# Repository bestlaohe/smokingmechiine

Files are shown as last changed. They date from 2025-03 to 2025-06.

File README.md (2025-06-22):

# 智能焊接吸烟机产品需求文档（PRD）

## 1. 产品概述
便携式多功能焊接辅助设备，集成烟雾抽排、活性炭过滤，焊接照明，电池供电，低功耗，滚轮调节亮度和风扇力度等功能，解决焊接场景下的健康防护与操作便利性问题。

## 2. 核心功能需求

### 2.1 智能吸烟系统
| 指标项 | 技术参数 | 补充说明 |
|---|---|---|
| 风扇类型 | 双滚珠轴承直流风扇（12V/200mA）  | 需提供噪音＜45dB的型号选项 |
| 风道设计 | 螺旋集烟罩+可拆卸滤网 | 滤网需支持水洗重复使用 |
| 调节方式 | 手动无级调速（200-2000rpm） | 响应时间＜3秒 |
| 控制方式 | TIM1_CH2N输出PWM信号(PA2) | PWM频率25KHz，占空比10%-100% |
| 软启动保护 | 0.5秒渐进加速 | 避免启动电流过大 |

### 2.2 专业照明系统
| 组件 | 规格要求 |
|---|---|
| LED光源 | 显色指数≥90，色温5000K±10%，光通量≥800lm | |
| 调光范围 | 10%-100%无级调节 |
| 控制方式 | TIM1_CH1N输出PWM信号(PD0) |
| PWM参数 | 频率2KHz，占空比10%-100% |

### 2.3 人机交互

**控制逻辑：**
1. 短按功能键（0.5s）：通过中断直接处理，切换风扇/灯光控制模式
2. 旋转编码器：在主循环中处理，调节当前模式参数
3. 状态更新：在页面显示函数中统一处理风扇、照明、电池状态更新

**输入设备规格：**
- 旋转编码器：用于调节参数，带有A/B相信号输出
- 功能按键：集成在旋转编码器中，用于切换控制模式
- 检测机制：通过CH32V003端口中断方式检测旋转和按下事件

**显示屏UI规范：**
采用128×128像素GC9107彩色屏幕，实现分区式布局设计：

```
┌──────────────────────┐
│       标题栏         │ ← 0-20像素
├──────────────────────┤
│                      │
│      FAN: 75%        │ ← 21-55像素
│    [■■■■■□□]         │
│                      │
├──────────────────────┤
│                      │
│     LIGHT: 60%       │ ← 56-90像素
│    [■■■■□□□]         │
│                      │
├──────────────────────┤
│                      │
│      BAT: 82%        │ ← 91-125像素
│    [■■■■■■□□]        │
│      4.1V            │
└──────────────────────┘
```

显示内容要求：
- 采用垂直分区设计，清晰展示三个核心参数
- 使用不同颜色区分功能区域：风扇(青色)、照明(黄色)、电池(绿色)
- 电池电量低于20%时进度条变为红色作为警示
- 界面刷新率≥5Hz，支持局部刷新以提高响应速度

### 2.4 显示屏背光
| 组件 | 规格要求 |
|---|---|
| 背光类型 | LED背光 |
| 调光范围 | 10%-100%无级调节 |
| 控制方式 | TIM1_CH3输出PWM信号(PC3) |
| 驱动芯片 | GC9107驱动，分辨率128×128像素，16位色 |

## 3. 结构需求

### 3.1 三防要求
| 参数 | 要求 |
|---|---|
| 防护等级 | IP54防护等级（防尘防溅水） |
| 外壳材料 | 阻燃ABS+硅胶防震包边 |

## 4. 电源管理系统

### 4.1 电池配置
| 参数 | 规格 |
|---|---|
| 电芯类型 | 21700锂离子电池×2（并联） |
| 标称容量 | 5000mAh/3.7V |

### 4.2 续航能力
- 满负荷（风扇+灯光）：≥2h
- 节能模式：≥8h

### 4.3 充电特性
```mermaid
graph TD
    A[Type-C输入] --> B(TP4057管理IC)
    B --> C[恒流充电 1A]
    C --> D[电压≥4.2V转恒压]
    D --> E[截止电流≤100mA停充]
```

## 5. 可靠性要求
| 测试项目 | 验收标准 |
|---|---|
| 高温老化 | 85℃环境下连续工作4小时 |
| 振动测试 | 5-500Hz随机振动3小时 |
| 按键寿命 | 5万次循环无失效 |

## 6. 合规性要求
- 电磁兼容：EN 61000-6-3
- 安规认证：UL 60745-1
- 环保认证：RoHS 2.0

## 7. 成本目标
| BOM分类 | 目标成本（千台量级） |
|---|---|
| 电子部件 | ≤30 |
| 结构件 | ≤50 |
| 合计 | ≤80 |

## 版本记录
| 版本 | 日期 | 修改说明 |
|---|---|---|
| v1.0 | 2023-08-25  | 初始版本 |
| v1.1 | 2023-08-27  | 补充EMC测试要求 |
| v1.2 | 2023-09-20  | 更新UI设计规范 | 
| v1.3 | 2023-10-15  | 调整PWM控制参数，同步软件设计 |

---

## 附录
该文档采用模块化结构设计，包含：
1. 参数表格化呈现关键指标
2. 交互逻辑的时序说明
3. 可视化UI示例
4. 成本分解明细
5. 版本控制记录

如果你觉得有用可以请我喝杯咖啡！
348f36a8640adfb87dfc8b97301e098a

【帅气的带焊接补光的吸烟机-哔哩哔哩】 https://b23.tv/cCpQy1C

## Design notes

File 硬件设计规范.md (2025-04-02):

# 智能焊接吸烟机电路连接定义（修订版）

## 1. 系统电路框图

```
┌──────────────┐          ┌───────────────────────┐          ┌────────────────┐
│              │          │                       │          │                │
│  电源管理模块 │◄─────────┤       主控制器        │──────────►│  显示控制模块  │
│  (TP4057)    │  电压检测 │     (CH32V003)       │  SPI通信  │  (GC9107)      │
│     │        │  充电状态 │                       │          │                │
└─────┼────────┘          └───┬───────┬───────┬───┘          └────────────────┘
      │                       │       │       │
      │                       │       │       │
      │                   PWM控制   PWM控制  旋钮编码
      │                   (PA2)    (PD0)    及按键
      ▼                       │       │       │
┌──────────────┐          ┌───▼───────▼───┐   │    ┌────────────────┐
│ 4.2V锂电池   │          │               │   │    │                │
│              │◄─┐   ┌───►│ 12V升压模块  │   └───►│  人机交互模块  │
└──────────────┘  │   │    │ (MT3608)     │        │  (旋钮+按键)   │
                  │   │    └───┬───────┬──┘        └────────────────┘
            电池管理   │        │       │
            保护电路   │        │       │
                  │   │      12V     12V
                  │   │        │       │
                  │   │        ▼       ▼
                  │   │    ┌──────┐  ┌──────┐
                  │   │    │      │  │      │
                  │   └────┤ 风扇 │  │ 射灯 │
                  │        │ 驱动 │  │ 驱动 │
                  │        └──┬───┘  └──┬───┘
                  │           │         │
                  │           ▼         ▼
                  │        ┌──────┐  ┌──────┐
                  └────────┤      │  │      │
                           │ 风扇 │  │ 射灯 │
                           │ 5cm  │  │ 12V  │
                           └──────┘  └──────┘
```

## 2. 模块间连接关系

### 2.1 主控制器与显示模块连接

| CH32V003引脚 | GC9107引脚 | 信号类型 | 说明 |
|---|---|---|---|
| PC0 | RES | 数字输出 | 复位信号 |
| PC2 | DC | 数字输出 | 数据/命令选择 |
| PC3 | BLK | PWM输出  | 背光亮度控制 |
| PC4 | CS | 数字输出 | SPI片选信号 |
| PC5 | SCL | 数字输出 | SPI时钟信号 |
| PC6 | SDA | 数字输出 | SPI数据信号 |
| 3.3V | VCC | 电源 | 显示模块供电 |
| GND | GND | 电源 | 系统地 |

### 2.2 主控制器与风扇控制电路连接

| CH32V003引脚 | 连接至 | 信号类型 | 说明 |
|---|---|---|---|
| PA2 | MOSFET栅极 | PWM输出  | 控制风扇转速(25KHz) |
| GND | MOSFET源极 | 电源 | 系统地 |
| 12V电源 | 风扇正极 | 电源 | 经MOSFET漏极连接 |

### 2.3 主控制器与LED射灯模块连接

| CH32V003引脚 | 连接至 | 信号类型 | 说明 |
|---|---|---|---|
| PD0 | MOSFET栅极 | PWM输出  | 控制射灯亮度(2KHz) |
| GND | MOSFET源极 | 电源 | 系统地 |
| 12V电源 | 射灯正极 | 电源 | 经MOSFET漏极连接 |

### 2.4 主控制器与人机交互控件连接

| CH32V003引脚 | 连接至 | 信号类型 | 说明 |
|---|---|---|---|
| PD2 | 功能按键 | 数字输入 | 短按切换模式/长按复位 |
| PD3 | 编码器B相 | 数字输入 | 检测旋转方向 |
| PD4 | 编码器A相 | 数字输入 | 检测编码器旋转 |

### 2.5 主控制器与电源管理模块连接

| CH32V003引脚 | 连接至 | 信号类型 | 说明 |
|---|---|---|---|
| PA1 | 电压分压器输出 | 模拟输入 | 检测电池电压 |
| PC1 | 充电IC状态引脚 | 数字输入 | 检测充电状态 |

## 3. 电源管理设计

### 3.1 充电电路设计

基于TP4057锂电池充电管理芯片，主要参数如下：
- 充电电流：1A (通过RPROG电阻设置)
- 充电截止电压：4.2V
- 涓流充电阈值：2.9V
- 充电截止电流：100mA

```
                      VCC
                       │
                       ▼
           ┌───────────┴────────┐
           │                    │
USB 5V ────┤ VIN       VBAT     ├──── 电池正极
           │                    │
           │      TP4057        │
           │                    │
GND ───────┤ GND       STAT     ├──── PC1 (充电状态)
           │                    │
           │           PROG     ├──── RPROG (1.2K)
           │                    │
           └────────────────────┘
```

### 3.2 DC-DC升压电路
基于MT3608升压芯片，将电池的3.7-4.2V电压升压到12V，为风扇和射灯供电：

```
            ┌───────┐              ┌─────┐
电池正极 ───┤EN     │              │     │
            │       │      ┌───────┤L1   │
            │MT3608 ├──────┤       │     │
            │       │      │       └──┬──┘
GND ────────┤GND   SW├──────┘          │
            │       │          ┌───────┴────┐
            └───┬───┘          │            │
                │              │  肖特基二极管 │
                │              │            │
                └──────────────┤      │     │
                               │      ▼     │
                               └─────────┬──┘
                                         │
                                         ▼
                                        12V输出
```

### 3.3 PWM控制电路

风扇和射灯均采用N-MOSFET低边驱动方式，通过PWM控制功率。电路如下：

```
        12V
         │
         ▼
     ┌───┴───┐
     │       │
     │ 风扇/ │
     │ 射灯  │
     │       │
     └───┬───┘
         │
         │
         ▼
    ┌────┴─────┐
    │D         │
    │  MOSFET  │
    │S    G    │
    └┬────┬────┘
     │    │
     │    ├──── 100Ω ────┬─── PWM信号(PA2/PD0)
     │    │              │
     │    └─── 10KΩ ─────┘
     ▼
    GND
```

### 3.4 电源分配

| 模块名称 | 供电电压  | 最大电流 | 来源 |
|---|---|---|---|
| CH32V003控制器 | 3.3V | 50mA | LDO稳压器 |
| GC9107显示模块 | 3.3V | 20mA | LDO稳压器 |
| LED射灯模块 | 12V | 41mA | DC-DC升压模块  |
| 风扇驱动电路 | 12V | 200mA | DC-DC升压模块  |

### 3.5 电池保护电路

采用专用锂电池保护IC，提供以下保护功能：
- 过充保护电压：4.25V
- 过放保护电压：2.9V
- 过流保护阈值：3A
- 短路保护

## 4. 关键元器件清单

| 元件类别 | 型号 | 数量 | 关键参数 |
|---|---|---|---|
| 主控制器 | CH32V003F4P6 | 1 | RISC-V，TSSOP20封装 |
| 显示驱动 | GC9107 | 1 | 分辨率：128×128，SPI接口|
| 电源管理 | TP4057 | 1 | 单节锂电池充电IC |
| 锂电池 | 18650/21700 | 1 | 3.7V/4.2V, 3000mAh |
| DC-DC转换| MT3608 | 1 | 输入3.7V，输出12V，效率>85%|
| MOSFET驱动| AO3400 | 2 | N沟道MOSFET，3.5A，20V  |
| 编码器 | EC11 | 1 | 带按键旋转编码器 |
| 风扇 | 5cm双滚珠风扇 | 1 | 12V, 200mA, <45dB |
| LED射灯  | 高亮LED模组 | 1 | 12V, 41mA, 显色指数≥90  |

## 5. PCB布局注意事项

1. **电源部分**
   - 充电IC周围布局需考虑散热
   - 电源走线宽度不小于1.5mm
   - 在电池接口附近设置保险丝
   - 升压电路需良好布局，减小EMI

2. **信号部分**
   - SPI信号线尽量短而粗
   - 模拟信号和数字信号分区布局
   - PWM信号线要远离敏感模拟信号

3. **布局分区**
   - 高压/高流部分与信号处理电路隔离
   - 注意风扇PWM驱动和LED驱动的散热设计
   - 显示模块单独一个区域，尽量减少干扰
   - 升压电路独立布局，并做好EMI抑制

## 6. 电源预算

### 6.1 不同工作模式下的功耗

| 工作模式 | 风扇功率 | 射灯功率 | 控制电路功率 | 总功耗 | 电池续航 |
|---|---|---|---|---|---|
| 满功率模式 | 2.4W | 0.5W | 0.2W | 3.1W | ≥1.8h |
| 节能模式 | 0.6W | 0.1W | 0.2W | 0.9W | ≥6h |
| 仅吸烟模式 | 2.4W | 0W | 0.2W | 2.6W | ≥2.5h |
| 仅照明模式 | 0W | 0.5W | 0.2W | 0.7W | ≥7h |
| 待机模式 | 0W | 0W | 0.05W | 0.05W  | ≥120h |

### 6.2 充电时间估算

- 电池容量：3000mAh
- 充电电流：1A
- 理论充电时间：约3小时
- 实际充电时间（考虑效率）：约3.5小时

## 7. 接口定义

### 7.1 外部接口

| 接口名称 | 接口类型 | 位置 | 说明 |
|---|---|---|---|
| 充电接口 | Type-C | 底部 | 5V/2A输入 |
| 风扇出风口 | 圆形网罩 | 顶部 | 导出焊接烟雾 |
| 磁吸底座接口 | 磁性接触面 | 背部 | 用于固定设备位置  |
| 电源开关 | 滑动开关 | 侧面 | 总电源开关 |

### 7.2 内部测试点

| 测试点名称 | 连接至 | 电压范围 | 说明 |
|---|---|---|---|
| TP1 | 电池电压 | 3.0V-4.2V  | 监测电池电压 |
| TP2 | 系统3.3V | 3.3V±5% | 检查稳压器输出 |
| TP3 | 12V电源线 | 12V±5% | 检查升压电路输出 |
| TP4 | MCU复位线 | 0V/3.3V | 手动复位系统 |
| TP5 | GND | 0V | 系统地 |

## 8. 机械结构与电路配合注意事项

1. 电池仓设计需考虑散热和防震
2. 显示屏位置需确保用户操作便利性
3. 旋钮和按键位置要便于单手操作
4. 风扇进风口避免灰尘直接进入电路板区域
5. 射灯散热设计要充分
6. 预留足够的维修和更换空间

## 9. 版本历史

| 版本号 | 日期 | 主要变更 |
|---|---|---|
| V0.1 | 2023-09-01 | 初版电路定义 |
| V0.2 | 2023-10-01 | 修订电路连接，明确PWM控制方式 |
| V0.3 | 2023-10-15 | 优化电源设计，更新元器件清单  |

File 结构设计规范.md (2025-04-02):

# 智能焊接吸烟机结构设计规范

## 1. 总体结构布局

### 1.1 多视图结构表示

**■ 主视图（主要功能区域划分）**
```
┌───────────────────────────────┐
│       顶部平面交互区域         │
│       ┌─────────────┐         │
│       │ 可调节射灯区 │         │
│       └─────────────┘         │
│ ┌────┐   ┌─────┐   ┌────┐    │
│ │按键 │   │ LCD │   │滚轮│    │
│ └────┘   │(40°)│   └────┘    │
│           └─────┘             │
│           主控区域             │
│     ┌───────────────────┐     │
│     │   电路控制单元     │     │
│     └───────────────────┘     │
├───────────────────────────────┤
│                               │
│           风扇舱室             │
│       ┌───────────────┐       │
│       │  吸烟风扇单元  │       │
│       └───────────────┘       │
├───────────────────────────────┤
│           电源区域             │
│    ┌─────────────────────┐    │
│    │    电池与充电电路    │    │
│    └─────────────────────┘    │
├───────────────────────────────┤
│       磁吸底座/充电接口        │
└───────────────────────────────┘
```

**■ 侧视图（结构剖面）**
```
      ┌───────────────┐
      │   射灯(可调)   │
      │      │        │
      │      │        │
      │      ▼        │
      │   LCD(40°)    │
      │               │
      ├───────────────┤
      │               │
      │    风扇单元    │
      │    ↑↓↑↓↑      │
      ├───────────────┤
      │               │
      │   主控电路板   │
      │               │
      ├───────────────┤
      │   电池仓室     │
      │               │
      └───────────────┘
```

**■ 俯视图（顶部布局）**
```
    ┌───────────────────┐
    │                   │
    │    ┌─────────┐    │
    │    │ 射灯单元 │    │
    │    └─────────┘    │
    │                   │
    │ ┌───┐ ┌───┐ ┌───┐ │
    │ │   │ │   │ │   │ │
    │ │按键│ │LCD │ │滚轮│ │
    │ │   │ │   │ │   │ │
    │ └───┘ └───┘ └───┘ │
    │                   │
    └───────────────────┘
```

### 1.2 组件位置与功能关系

| 功能区域 | 主要组件 | 位置描述 | 功能特性 |
|---|---|---|---|
| 顶部照明区 | 可调节射灯 | 顶部上方区域 | 工作区照明，任意角度调节 |
| 顶部交互区 | LCD显示屏 | 射灯下方居中，40°倾角 | 状态显示，视角优化 |
| 顶部交互区 | 功能按键 | LCD左侧 | 模式切换，防水设计 |
| 顶部交互区 | 调节滚轮 | LCD右侧 | 参数精确调节，触感反馈 |
| 控制区 | 主控电路 | LCD下方，风扇上方 | 系统控制，优化散热通道 |
| 中部 | 吸烟风扇 | 主控下方 | 下进上出气流设计，最大化吸烟效率 |
| 底部 | 电池仓 | 整体底部 | 低重心设计，快速更换机制 |
| 底部 | 磁吸底座 | 底面 | 工作台固定，自由调整位置 |

## 2. 结构重心设计优化

### 2.1 重量分布比例
- 底部占总重量：65-70%（电池和电源管理）
- 中部占总重量：20-25%（控制电路和风扇）
- 顶部占总重量：5-10%（显示屏、射灯和控制元件）

### 2.2 低重心设计要素
- 电池放置于底部最低位置，作为主要重量元素
- 所有电源管理电路集中于电池舱上方
- 风扇单元位于设备中上部，采用轻量化设计
- 显示屏与射灯组件使用轻量材料，减轻顶部重量

## 3. 尺寸与外形设计

### 3.1 基本尺寸
- 整体高度：≤120mm
- 最大直径/宽度：≤80mm
- 整体重量：≤350g

### 3.2 人体工学设计
- 握持区域设计弧形轮廓，适合单手握持
- 旋钮位置偏向右侧，便于右手拇指操作
- 底部加宽设计，提高稳定性

## 4. 模块化布局设计

### 4.1 电源模块（底部）
- 采用分体式结构，可独立维护
- 内置3.7V锂电池单元，位于最低点
- 电池仓采用侧向抽屉式设计，单手操作即可更换
- 电池固定采用磁吸+弹簧卡扣双重保护，防震动松脱
- 电源管理电路位于电池上方，形成独立热区

### 4.2 控制模块（中部）
- 主控板采用双面悬挂式安装，减震防护
- 电路板设计为多层叠板结构，优化空间利用率
- 周围设计完整散热通道，与风扇气流相通
- 关键元器件配置独立散热片，导热通道引向机壳

### 4.3 风扇模块（中上部）
- 风扇采用密封设计，形成独立气流通道
- 进风口贯穿设备中部侧面，设计为360°环形进风
- 出风口位于顶部，与工作区域正对
- 采用定向风道设计，最大化吸烟效率
- 风扇固定采用减震垫圈，降低振动传递

### 4.4 顶部交互模块（集成式设计）
- 采用分层集成设计，形成完整的顶部操作界面
- 上层配置可调节射灯，采用嵌入式设计
- 中层设置LCD显示屏（居中），40°固定倾角
- 中层左侧设置功能按键，右侧设置调节滚轮
- 操作区域采用特殊防滑材料，提高操作舒适度
- 所有顶部元件采用一体化布线设计，减少接插件使用

### 4.5 磁吸底座系统
- 底部设计扁平化磁吸阵列，4点分布
- 磁铁单元采用内嵌式设计，表面平整无突起
- 配套工作台底座采用可调节角度设计
- 底座集成TYPE-C充电接口，支持边充边用

## 5. 可调节射灯设计

### 5.1 射灯机构改进
- 位于顶部最上方区域，突出于操作平面
- 射灯底座与顶部外壳形成流线型过渡
- 采用双轴调节结构，支持水平和垂直方向调节
- 球形万向节内部采用摩擦力可调节设计
- 射灯支架采用内嵌式线缆设计，避免外露线缆
- 灯头整体可拆卸更换，便于维护

### 5.2 调节机构详细参数
- 水平方向调节角度：0-180°
- 垂直方向调节角度：0-60°
- 调节阻尼力：0.3-0.5N·m
- 灯体直径：≤20mm
- 灯臂长度：≤30mm

### 5.3 光学设计
- 聚光透镜：15°光束角
- 防眩光罩设计
- 透镜采用钢化玻璃，耐高温

## 6. 散热系统设计

### 6.1 被动散热设计
- 底部电源区域设计散热鳍片
- 外壳内侧设计导热通道
- 主控板周围留有5mm以上空气间隙

### 6.2 主动散热利用
- 风扇排气产生的负压辅助内部空气流通
- 侧面进风格栅设计，形成定向气流
- 关键热源（DC-DC模块、MOSFET）附近设置导热铝片

## 7. 材料选择

### 7.1 外壳材料
- 主体：PC+ABS阻燃材料（V0级）
- 底座：镍铬合金或钢材
- 风扇网罩：不锈钢网格

### 7.2 关键位置材料要求
- 射灯散热体：铝合金
- 握持区域：TPE软胶包覆
- 旋钮：铝合金，表面阳极氧化
- 显示屏保护镜片：强化玻璃

## 8. 人机交互设计

### 8.1 操作界面
- 形成上射灯、中LCD、左按键、右滚轮的布局设计
- 显示屏安装在射灯下方居中位置，倾斜角度40°
- 功能按键位于LCD左侧，突出外壳2-3mm
- 调节滚轮位于LCD右侧，突出外壳2-3mm
- 各元件间距保持4-6mm，避免误操作
- 电源开关：侧滑式，带防误触设计

### 8.2 指示设计
- 电源状态LED：底部可见
- 充电指示：底部边缘，充电时可见
- 模式指示：通过显示屏实现

### 8.3 人体工学
- 握持区弧度半径：30-35mm
- 表面处理：防滑纹理
- 重量平衡点：距底部30mm左右

## 9. 防护与安全设计

### 9.1 防尘防水
- 防护等级：IP42（防止1mm以上颗粒进入，防滴洒）
- 按键和旋钮密封设计
- 充电口防尘盖

### 9.2 防摔设计
- 底角缓冲设计，采用TPE材料
- 关键部件加固，承受1m自由落体
- 电池仓防震垫设计

### 9.3 热保护
- 射灯外壳最高温度限制：≤60℃
- 风扇启动温度：45℃
- 过热保护自动降功率

## 10. 装配与维护考虑

### 10.1 装配设计
- 模块化设计，分体式组装
- 螺钉数量：≤8个
- 卡扣连接：关键连接处采用金属增强卡扣

### 10.2 维修便利性
- 电池仓可独立打开更换
- 主控板维修仅需拆卸底部螺钉
- 风扇清洁通过可拆卸顶盖实现

### 10.3 使用寿命设计
- 外壳材料老化寿命：≥5年
- 按键/旋钮使用次数：≥100,000次
- 充电接口使用次数：≥10,000次
- 射灯调节机构使用次数：≥5,000次

## 11. 版本控制

| 版本号 | 日期 | 变更内容 |
|---|---|---|
| V1.0 | 2023-10-20 | 初始结构设计规范 |

## 12. 附录：关键结构尺寸图

**■ 剖面尺寸示意图**
```
           ┌────90mm────┐
           │             │
           │  射灯单元   │ 15mm
           │             │
           ├─────────────┤
    ┌──────┼─────────────┼──────┐
    │按键  │    LCD      │ 滚轮 │
    │      │   (40°)     │      │ 15mm
    └──────┴─────────────┴──────┘
           ├─────────────┤
           │             │
           │  主控单元   │ 20mm
           │             │
           ├─────────────┤
           │             │
           │  吸烟风扇   │ 30mm
           │             │
           ├─────────────┤
           │             │
           │  电池模块   │ 30mm
           │             │
           └─────────────┘
             磁吸底座     10mm
            总高120mm
```

**■ 重量分布示意图**
```
           ┌───────────┐
           │   10%     │  顶部区域
           ├───────────┤
           │           │
           │   25%     │  中部区域
           │           │
           ├───────────┤
           │           │
           │   65%     │  底部区域
           │           │
           └───────────┘
```

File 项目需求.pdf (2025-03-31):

# 智能焊接抽烟机产品需求文档（PRD）

# 1. 产品概述

便携式多功能焊接辅助设备，集成烟雾抽排、无影照明、磁吸定位三大核心功能，解决焊接场景下的健 康防护与操作便利性问题。

# 2. 核心功能需求

## 2.1 智能抽烟系统

指标项 | 技术参数 | 补充说明
风扇类型 | 双滚珠轴承直流风扇（12V/200mA） | 需提供噪音＜45dB的型号选项
风道设计 | 螺旋集烟罩+可拆卸滤网 | 滤网需支持水洗重复使用
调节方式 | 双模式： • 自动模式（基于PM2.5传感器） • 手动无级调速（200-2000rpm） | 自动模式下响应时间＜3秒

## 2.2 专业照明系统

组件 | 规格要求
LED光源 | 显色指数≥90，色温5000K±10%，光通量≥800lm
光学设计 | 蜂窝状均光板+120°广角透镜
调光范围 | 10%-100%无级调节，支持PWM调光（频率＞1000Hz防频闪）

## 2.3 人机交互

控制逻辑：

1. 短按功能键（0.5s）：切换风扇/灯光控制模式
2. 旋转编码器：调节当前模式参数

3. 长按功能键（3s）：复位默认参数

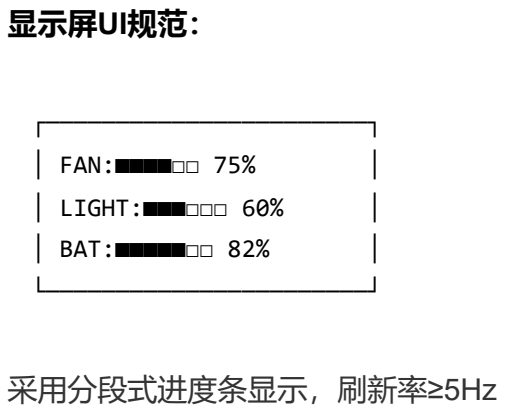
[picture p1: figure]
显示屏UI规范：; │ FAN:■■■■□□ 75%; │ LIGHT:■■■□□□ 60%; │ BAT:■■■■■□□ 82%; 采用分段式进度条显示，刷新率≥5Hz

# 3. 结构需求

## 3.1 磁吸系统

参数 | 要求
磁力规格 | 钕磁铁N35级，单点吸附力≥3kgf
万向调节 | 支持球头关节±15°角度锁定

## 3.2 三防要求

参数 | 要求
防护等级 | IP54防护等级（防尘防溅水）
外壳材料 | 阻燃ABS+硅胶防震包边

# 4. 电源管理系统

## 4.1 电池配置

参数 | 规格
电芯类型 | 21700锂离子电池×2（并联）
标称容量 | 5000mAh/3.7V

## 4.2 续航能力

## 4.3 充电特性

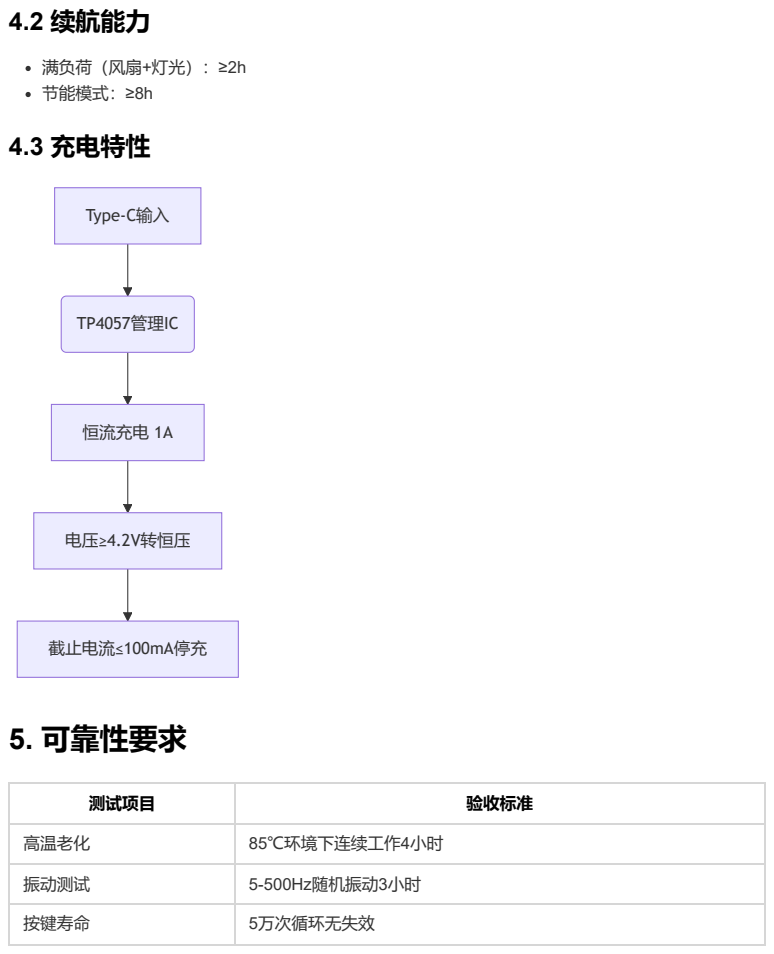
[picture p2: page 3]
Type-C输入; TP4057管理IC; 恒流充电 1A; 电压≥4.2V转恒压; 截止电流≤100mA停充; 5. 可靠性要求

满负荷（风扇+灯光）：≥2h
节能模式：≥8h

测试项目 | 验收标准

高温老化 | 85℃环境下连续工作4小时
振动测试 | 5-500Hz随机振动3小时
按键寿命 | 5万次循环无失效

# 6. 合规性要求

电磁兼容：EN 61000-6-3
安规认证：UL 60745-1
环保认证：RoHS 2.0

# 7. 成本目标

BOM分类 | 目标成本（千台量级）
电子部件 | ≤18.50
结构件 | ≤9.80
总装测试 | ≤5.20
合计 | ≤33.50

# 版本记录

版本 | 日期 | 修改说明
v1.0 | 2023-08-25 | 初始版本
v1.1 | 2023-08-27 | 补充EMC测试要求

附录

该文档采用模块化结构设计，包含：

1. 参数表格化呈现关键指标
2. 交互逻辑的时序说明
3. 可视化UI示例
4. 成本分解明细
5. 版本控制记录

可根据实际开发阶段需求扩展测试用例附录、接口定义等章节

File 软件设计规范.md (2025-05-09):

# 智能焊接吸烟机软件设计规范

## 1. 系统概述

本智能焊接吸烟机系统基于CH32V003微控制器（RISC-V架构），集成了风扇控制、LED照明控制、UI显示以及人机交互功能。系统采用模块化设计，各功能模块相对独立，便于维护和升级。

## 2. 功能模块定义

### 2.1 风扇控制模块

#### 2.1.1 功能描述
- 提供手动无级调速模式
- 在手动模式下提供200-2000rpm范围内的无级调速
- 提供风扇速度软启动功能，避免瞬时电流过大

#### 2.1.2 接口定义
```c
// PWM配置函数（使用已有代码）
void PWM_Config(u16 Freq, u16 Duty);

// 定时器PWM通道初始化
// CH1N(PD0)-照明LED, CH2N(PA2)-风扇, CH3(PC3)-屏幕背光
void TIM1_Init(u16 arr, u16 psc, u16 duty_ch1n, u16 duty_ch2n, u16 duty_ch3);

// 单独设置各PWM通道占空比
void TIM1_SetCompare1N(u16 compare);   // 设置照明LED占空比(PD0)
void TIM1_SetCompare2N(u16 compare);   // 设置风扇占空比(PA2)
void TIM1_SetCompare3(u16 compare);    // 设置屏幕背光占空比(PC3)

// 设置风扇转速百分比
void FAN_SetSpeed(uint8_t percentage);

// 获取当前风扇转速百分比
uint8_t FAN_GetSpeed(void);
```

### 2.2 照明控制模块

#### 2.2.1 功能描述
- 控制LED光源亮度，支持10%-100%无级调光
- 实现PWM调光，频率>1000Hz防频闪

#### 2.2.2 接口定义
```c
// 设置照明亮度百分比（10-100%）
void LIGHT_SetBrightness(uint8_t percentage);
```

### 2.3 人机交互模块

#### 2.3.1 功能描述
- 实现按键检测和处理：短按切换控制模式，长按复位默认参数
- 实现旋转编码器输入检测
- 控制显示屏UI更新

#### 2.3.2 接口定义
```c
// 人机交互初始化
void HMI_Init(void);

// 编码器相关函数（使用已有代码）
void Encoder_Init(u16 arr, u16 psc);
void Encoder_Scan();

// 获取当前控制模式（0：风扇控制，1：灯光控制）
uint8_t HMI_GetControlMode(void);

// 人机交互模块周期性处理函数（主循环中调用）
void HMI_Process(void);
```

### 2.4 显示驱动模块

#### 2.4.1 功能描述
- 基于GC9107驱动芯片实现显示控制
- 提供基本图形绘制函数
- 显示进度条、文字和图标

#### 2.4.2 接口定义
```c
// 显示初始化（使用已有代码）
void Screen_Init(UBYTE Scan_dir);
void LCD_SHOW_API_INIT();

// 清屏
u8 Screen_Clear(UWORD Xstart, UWORD Ystart, UWORD Xend, UWORD Yend, UWORD Color);

// 绘制图形和文字（使用已有代码）
void Paint_DrawLine(UWORD Xstart, UWORD Ystart, UWORD Xend, UWORD Yend, UWORD Color, DOT_PIXEL Line_width, LINE_STYLE Line_Style);
void Paint_DrawRectangle(UWORD Xstart, UWORD Ystart, UWORD Xend, UWORD Yend, UWORD Color, DOT_PIXEL Line_width, DRAW_FILL Filled);
void Paint_DrawString(UWORD Xstart, UWORD Ystart, const char * pString, sFONT* Font, UWORD Color_Background, UWORD Color_Foreground, const char offsetAcsii, UWORD changeColorNumber);
void Paint_DrawNum(UWORD Xpoint, UWORD Ypoint, int32_t Nummber, sFONT* Font, UWORD Color_Background, UWORD Color_Foreground);

// 背光控制
void Screen_SetBackLight(UWORD Value);

// 低功耗模式
void Screen_EnterSleepMode(void);
void Screen_ExitSleepMode(void);

// 页面显示（使用已有代码）
void show_page();
```

### 2.5 电源管理模块

#### 2.5.1 功能描述
- 电池电量监测
- 充电状态监测
- 低功耗模式管理

#### 2.5.2 接口定义
```c
// 电源管理初始化
void Battery_Init(void);
void Battery_DeInit(void);

// 获取电池电量百分比
uint8_t POWER_GetBatteryLevel(void);

// 获取充电状态（0：未充电，1：充电中，2：充电完成）
uint8_t POWER_GetChargeStatus(void);

// 低功耗相关函数（使用已有代码）
void refresh_SleepCounter(int newtime);
void Sleep_Scan(void);
void system_enter_sleep(void);
void AWU_Init(void);

// 进入待机模式
void PWR_EnterSTANDBYMode(uint8_t PWR_STANDBYEntry);
```

## 3. 引脚定义
  
### 3.1 CH32V003引脚分配

| 引脚 | 功能定义 | 原理图标记  | 复用功能 | 说明 |
|---|---|---|---|---|
| PA1  | 电池电量检测 | BATTERY | A1 | ADC输入，检测电池电压 |
| PA2  | 风扇PWM输出 | EN_MOTOR  | A0/T1CH2N | TIM1_CH2N输出，控制风扇转速 |
| PC0  | 显示屏RST | LORA_RST  | 通用GPIO | 显示屏复位信号，低电平有效 |
| PC1  | 充电状态检测 | CHARGE | SDA/T1BKIN | GPIO输入，检测充电状态 |
| PC2  | 显示屏DC | SCREEN_DC | SCL/T1BKIN | 数据/命令选择线 |
| PC3  | 屏幕背光PWM控制 | SCREEN_BL | T1CH3/T1CH1N | TIM1_CH3输出，控制背光PWM |
| PC4  | 显示屏SPI_CS | SCREEN_CS | A2 | SPI片选信号 |
| PC5  | 显示屏SPI_SCK | SCL | SCK/T1ETR | SPI时钟信号 |
| PC6  | 显示屏SPI_MOSI | MOSI | MOSI/T1CH1 | SPI数据输出 |
| **PC7**  | **备用** | - | PCLK/T1ETR | **未使用的备用引脚** |
| PD0  | 照明LED PWM输出 | LORA_CS | T1CH1N | TIM1_CH1N输出，控制LED亮度 |
| PD1  | 调试/烧录接口 | SWIO | SWIO/AETR2 | 烧录和调试用SDIO接口 |
| PD2  | 功能按键输入 | SW | A3/T1CH1 | 外部中断，检测按键按下 |
| PD3  | 旋转编码器B相 | SWB | A4/T2CH2 | GPIO输入，检测旋转方向 |
| PD4  | 旋转编码器A相 | SWA | A7/UCK | 外部中断，检测编码器旋转 |
| PD5  | 串口TX | TX | UTX/T1CH1 | UART数据发送线 |
| **PD7**  | **备用** | SCREEN_RST| NRST/T2CH4 | **系统复位引脚（备用）低电平** |

### 3.2 GC9107显示驱动芯片接口定义

| 引脚号 | 引脚名称 | 连接到MCU | 原理图连接 | 说明 |
|---|---|---|---|---|
| 1 | GND | 系统地 | 系统地 | 电源地 |
| 2 | VCC | 3.3V电源 | 3.3V电源 | 电源正极 |
| 3 | SCL | PC5 | PC5 | SPI时钟信号 |
| 4 | SDA | PC6 | PC6 | SPI数据信号 |
| 5 | RES | PC0 | PC0 | 复位信号，低电平有效 |
| 6 | DC | PC2 | PC2 | 数据/命令选择，高=数据，低=命令 |
| 7 | CS | PC4 | PC4 | 片选信号，低电平有效 |
| 8 | BLK | PC3 | PC3 | 背光控制，PWM调节 |

## 4. 界面设计

### 4.1 屏幕参数

| 参数名称 | 参数值 | 说明 |
|---|---|---|
| 屏幕尺寸 | 128×128像素 | GC9107驱动的彩色屏幕 |
| 颜色深度 | 16位 | RGB565格式，65536色 |
| 字体尺寸(大)  | 16×16像素 | 用于标题和重要数值显示 |
| 字体尺寸(小)  | 12×12像素 | 用于标签和单位显示 |

### 4.2 主界面布局

主界面采用垂直分区设计，分为三个主要功能区域，便于在小尺寸屏幕上清晰显示关键信息。

```
┌──────────────────────┐
│       标题栏         │ ← 0-20像素
├──────────────────────┤
│                      │
│      FAN: 75%        │ ← 21-55像素
│    [■■■■■□□]         │
│                      │
├──────────────────────┤
│                      │
│     LIGHT: 60%       │ ← 56-90像素
│    [■■■■□□□]         │
│                      │
├──────────────────────┤
│                      │
│      BAT: 82%        │ ← 91-125像素
│    [■■■■■■□□]        │
│      4.1V            │
└──────────────────────┘
```

### 4.3 元素布局详细说明

| 界面元素 | 位置(x,y) | 尺寸(宽×高)  | 说明 |
|---|---|---|---|
| 标题文本 | (32,2) | 64×16 | 居中显示"吸烟机" |
| 风扇图标 | (10,28) | 16×16 | 风扇状态区域左侧 |
| 风扇文本 | (30,28) | 32×16 | 显示"FAN:"和百分比值 |
| 风扇进度条 | (20,45) | 88×10 | 7段进度条，显示风扇速度 |
| 照明图标 | (10,63) | 16×16 | 照明状态区域左侧 |
| 照明文本 | (30,63) | 32×16 | 显示"LIGHT:"和百分比值 |
| 照明进度条 | (20,80) | 88×10 | 7段进度条，显示照明亮度 |
| 电池图标 | (10,98) | 16×16 | 电池状态区域左侧 |
| 电池文本 | (30,98) | 32×16 | 显示"BAT:"和百分比值 |
| 电池进度条 | (20,115) | 88×10 | 8段进度条，显示电池电量 |
| 电压值 | (48,110) | 32×12 | 显示实际电池电压 |

### 4.4 颜色方案

| 界面元素 | 前景色(RGB565)  | 背景色(RGB565) | 说明 |
|---|---|---|---|
| 背景 | - | 0x0000(黑) | 屏幕背景色 |
| 标题文本 | 0xFFFF(白) | 0x0000(黑) | 标题文字颜色 |
| 风扇区域 | 0x07FF(青) | 0x0000(黑) | 风扇相关元素颜色 |
| 照明区域 | 0xFFE0(黄) | 0x0000(黑) | 照明相关元素颜色 |
| 电池区域 | 0x07E0(绿) | 0x0000(黑) | 电池相关元素颜色，低于20%变红  |
| 进度条(满) | 同对应区域颜色 | 0x0000(黑) | 进度条填充部分颜色 |
| 进度条(空) | 0x7BEF(灰) | 0x0000(黑) | 进度条未填充部分颜色 |

## 5. 软件流程

### 5.1 主程序流程

```
开始
 │
 ├─ 系统初始化
 │   ├─ 时钟初始化
 │   ├─ GPIO初始化
 │   ├─ 中断初始化
 │   ├─ ADC初始化
 │   ├─ PWM初始化（定时器1用于风扇(CH2N)、照明(CH1N)、背光(CH3)）
 │   ├─ SPI初始化
 │   └─ 其他外设初始化
 │
 ├─ 功能模块初始化
 │   ├─ 风扇控制初始化
 │   ├─ 照明控制初始化
 │   ├─ 显示驱动初始化
 │   ├─ 人机交互初始化
 │   └─ 电源管理初始化
 │
 └─ 主循环
     │
     ├─ 处理编码器输入
     ├─ 执行低功耗管理
     ├─ 显示页面更新
     │   ├─ 更新风扇状态
     │   ├─ 更新照明状态
     │   ├─ 更新电池状态
     │   └─ 刷新显示内容
     └─ 系统状态监测
```

### 5.2 中断服务流程

#### 5.2.1 按键中断
```
进入中断
 │
 ├─ 记录按键按下时间
 ├─ 消抖处理
 ├─ 判断按键类型（短按/长按）
 │   ├─ 短按：切换控制模式（风扇/灯光）
 │   └─ 长按：复位为默认参数
 ├─ 设置按键事件标志
 └─ 退出中断
```

#### 5.2.2 编码器中断
```
进入中断
 │
 ├─ 读取B相状态
 ├─ 根据B相状态判断旋转方向
 ├─ 设置编码器事件标志
 └─ 退出中断
```

## 6. 软件参数配置

### 6.1 系统参数

| 参数名称 | 参数值 | 说明 |
|---|---|---|
| SYS_CLOCK | 48MHz | 系统时钟频率 |
| TICK_TIME | 1ms | 系统基本时间单位 |
| ADC_SAMPLE_CYCLE | 100ms | ADC采样周期 |
| UI_UPDATE_CYCLE  | 200ms | UI更新周期 |
| BAT_CHECK_CYCLE  | 30s | 电池电量检查周期 |

### 6.2 风扇控制参数

| 参数名称 | 参数值 | 说明 |
|---|---|---|
| FAN_PWM_FREQ | 25KHz | 风扇PWM频率 |
| FAN_MIN_DUTY | 10% | 风扇最小占空比 |
| FAN_MAX_DUTY | 100% | 风扇最大占空比 |
| FAN_STARTUP_TIME | 500ms | 风扇软启动时间 |

### 6.3 照明控制参数

| 参数名称 | 参数值 | 说明 |
|---|---|---|
| LIGHT_PWM_FREQ | 2KHz | 照明PWM频率 |
| LIGHT_MIN_DUTY | 10% | 照明最小占空比 |
| LIGHT_MAX_DUTY | 100% | 照明最大占空比 |

### 6.4 电源管理参数

| 参数名称 | 参数值 | 说明 |
|---|---|---|
| BAT_FULL_VOL | 4.2V | 电池满电电压 |
| BAT_LOW_VOL | 3.3V | 电池低电电压 |
| BAT_EMPTY_VOL | 3.0V | 电池空电电压 |
| LOW_POWER_TIMEOUT| 5min | 无操作进入低功耗模式时间 |

## 7. 开发工具及环境

- 开发环境：MounRiver Studio（基于Eclipse）
- 编译器：RISC-V GCC
- 调试器：WCH-Link
- 编程语言：C语言
- 固件库：CH32V003官方固件库

## 8. 版本管理

| 版本号 | 日期 | 说明 |
|---|---|---|
| V0.1 | 2023-09-01 | 初始版本，基本功能实现 |
| V0.2 | 2023-09-10 | 添加电源管理模块 |
| V0.3 | 2023-09-20 | 优化UI显示和人机交互体验 | 
| V0.4 | 2023-09-25 | 移除PM2.5模块，简化风扇控制模式 |

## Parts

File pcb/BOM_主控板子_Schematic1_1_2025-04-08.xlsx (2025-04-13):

编号 | 数量 | 备注 | 位号 | 封装 | LCSC Price | LCSC Stock | JLCPCB Price | JLCPCB Stock
1 | 2 | 22uF | C1,C58 | C0603 | 0.2514 | 53160 | 0.251 | 239378
2 | 2 | 100nF | C2,C59 | C0603 | 0.042 | 0 | 0.042 | 0
3 | 2 | 100nF | C10,C11 | C0603 | 0.0918 | 54 | 0.0918 | 3005
4 | 1 | 4.7uf | C32 | C0603
5 | 3 | 100nF | C38,C39,C56 | C0603 | 0.0142 | 22129 | 0.0142 | 2650996
6 | 1 | 47pF | C40 | C0603 | 0.0205 | 2559 | 0.0205 | 497755
7 | 1 | 22uf | C41 | C0603
8 | 1 | 47uF | C55 | C0603 | 0.3564 | 16589 | 0.356 | 83591
9 | 1 | 1uf | C57 | C0603
10 | 1 | SS36 | D1 | SMA_L4.3-W2.6-LS5.2-RD | 0.2066 | 14019 | 0.207 | 125713
11 | 3 | B5819WS | D6,D7,D8 | SOD-323F_L1.7-W1.3-LS2.5-R-RD-1 | 0.0903 | 2714 | 0.0903 | 69749
12 | 1 | AFH34-S12FIA-1H | FPC1 | FPC-SMD_12P-P0.50_THD0509-12CL-GF | 0.8024 | 515 | 0.802 | 2306
13 | 3 | ZX-XH2.54-2PWT | H1,H5,U29 | CONN-SMD_2P-P2.54_MEGASTAR_ZX-XH2.54-2PWT | 0.3625 | 21833 | 0.363 | 98002
14 | 1 | PZ254V-11-04P | H2 | HDR-TH_4P-P2.54-V-M | 0.1384 | 33034 | 0.138 | 410618
15 | 1 | 22uH | L1 | IND-SMD_L5.0-W5.0 | 0.3586 | 4668 | 0.359 | 29097
16 | 1 | 4.7uH | L14 | L0603 | 0.1359 | 857 | 0.136 | 46361
17 | 1 | 2.2uH | L15 | L0603 | 0.1162 | 826 | 0.116 | 50344
18 | 3 | AO3401A | Q6,Q7,Q8 | SOT-23_L2.9-W1.3-P0.95-LS2.4-BR | 0.1982 | 28398 | 0.198 | 266402
19 | 1 | 1.5欧 | R1 | R0603
20 | 1 | 5.1k | R2 | R0603
21 | 2 | 1MΩ | R4,R5 | R0603
22 | 2 | 100kΩ | R43,R47 | R0603 | 0.0065 | 58495 | 0.0065 | 2589512
23 | 1 | 20kΩ | R44 | R0603 | 0.0066 | 15271 | 0.0066 | 2814966
24 | 1 | 200k | R45 | R0603
25 | 3 | 100k | R46,R68,R72 | R0603
26 | 2 | 5.1kΩ | R58,R59 | R0603 | 0.0066 | 51476 | 0.0066 | 6994351
27 | 1 | 2.2k | R62 | R0603
28 | 2 | 100kΩ | R63,R64 | R0603 | 0.0065 | 71140 | 0.0065 | 3744634
29 | 3 | 10k | R65,R67,R70 | R0603
30 | 1 | 1.6k | R66 | R0603
31 | 2 | 100欧 | R69,R71 | R0603
32 | 1 | TS24CA 250gf 013 | SW3 | SW-SMD_L4.7-W3.5-P3.35-EH | 0.1594 | 2837 | 0.159 | 33307
33 | 1 | CH32V003F4P6(TSSOP20) | U1 | OLIMEX_IC-FP:TSSOP20_Pitch-0.65mm_6.6x4.5x1.2mm
34 | 1 | ME4059ASPG-N | U4 | ESOP-8_L4.9-W3.9-P1.27-LS6.0-BL-EP | 1.5403 | 355 | 1.54 | 2175
35 | 1 | SL0805200 | U8 | F0805 | 0.4118 | 4210 | 0.412 | 25831
36 | 1 | ETA3425S2F | U22 | SOT-23-5_L2.9-W1.6-P0.95-LS2.8-BL | 2.71 | 16 | 2.71 | 61
37 | 1 | e5e8 | U23 | e5e8
38 | 1 | SS8050 | U25 | SOT-23-3_L2.9-W1.3-P1.90-LS2.4-BR | 0.0696 | 20818 | 0.0696 | 930226
39 | 1 | 水银开关 | U30 | 水银开关
40 | 1 | TP4057-42-SOT26-R | U37 | SOT-23-6_L2.9-W1.6-P0.95-LS2.8-BL | 0.8671 | 5088 | 0.867 | 22197
41 | 1 | MT3608 | U38 | SOT-23-6_L2.9-W1.6-P0.95-LS2.8-BL | 0.3993 | 27520 | 0.399 | 172342
42 | 1 | TYPE-C16PIN | USB2 | USB-C-SMD_TYPE-C16PIN | 0.4284 | 22277 | 0.428 | 161526

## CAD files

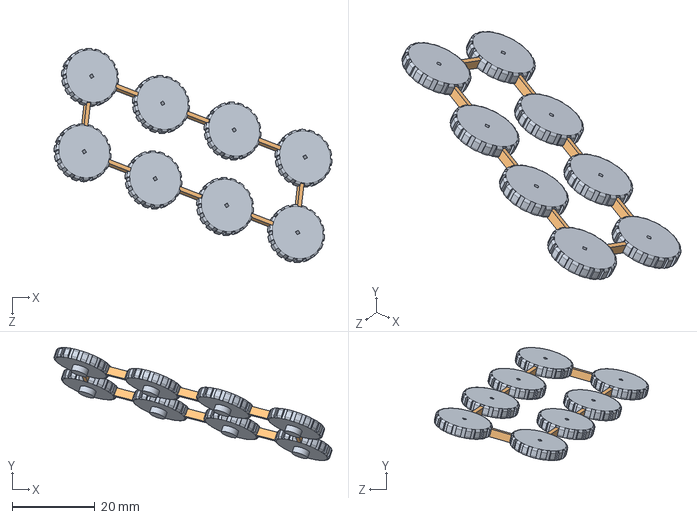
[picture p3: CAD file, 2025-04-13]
结构/组合打印/组合滚轮装配体.SLDASM
67.1 x 27.3 x 51.7 mm
滚轮 x 8
拼板连接 x 8

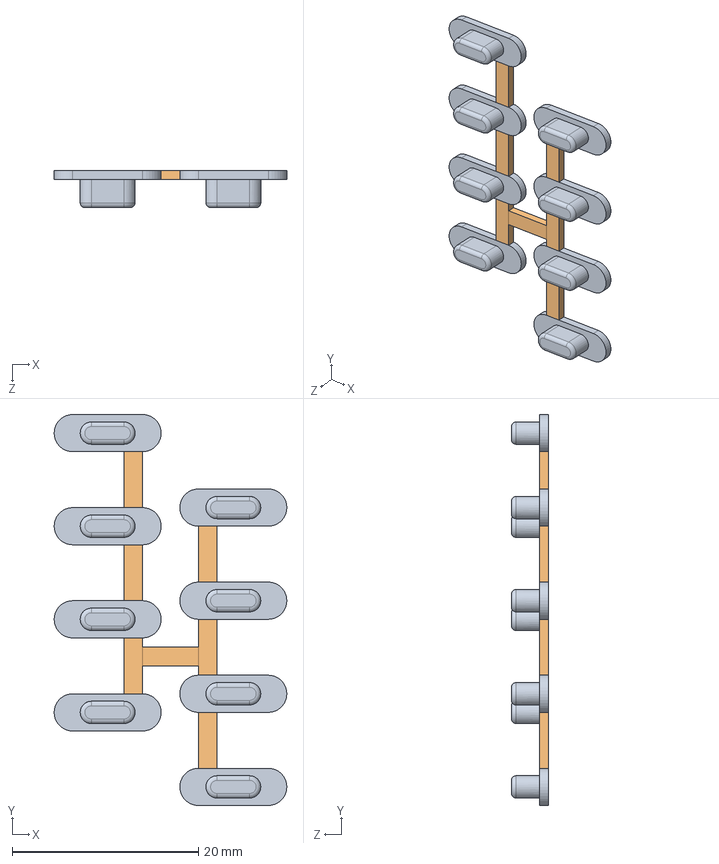
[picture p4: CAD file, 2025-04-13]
结构/组合打印/组合按键装配体.SLDASM
25.0 x 42.0 x 4.00 mm
按钮 x 8
拼板连接 x 7

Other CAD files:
结构/Qpvw-R72.SLDASM
结构/Qpvw-C10.SLDASM
结构/Qpvw-R62.SLDASM
结构/C0603_5_2.SLDASM
结构/Qpvw-R76.SLDASM
结构/SOT-23-6_L2.9-W1.6-P0.95-LS2.8-BL_1.SLDASM
结构/SOD-323F_L1.7-W1.3-LS2.5-R-RD-1_5.SLDASM
结构/Qpvw-H6.SLDASM
结构/Qpvw-U40.SLDASM
结构/FPC-SMD_12P-P0.50_THD0509-12CL-GF_4.SLDASM
结构/Qpvw-R5.SLDASM
结构/R0603_3_2.SLDASM
结构/Qpvw-D7.SLDASM
结构/CONN-SMD_3P-P1.00_HDGC_HDGC1002WV-S-3P.SLDASM
结构/e5e8_4.SLDASM
结构/Qpvw-R2.SLDASM
结构/3D_吸烟板_2025-04-10.SLDASM
结构/3D_吸烟板_2025-04-101.SLDASM
结构/3D_吸烟板_2025-04-102.SLDASM
结构/Board.SLDPRT
结构/Board_1.SLDPRT
结构/Board_2.SLDPRT
结构/Board_3.SLDPRT
结构/Board_4.SLDPRT
结构/C0603.SLDASM
结构/C0603_1.SLDASM
结构/C0603_1_2.SLDASM
结构/C0603_2.SLDASM
结构/C0603_3.SLDASM
结构/C0603_3_2.SLDASM
结构/C0603_4.SLDASM
结构/C0603_4_2.SLDASM
结构/C0603_5.SLDASM
结构/COMPOUND.SLDPRT
结构/COMPOUND_1.SLDPRT
结构/COMPOUND_10.SLDPRT
结构/COMPOUND_11.SLDPRT
结构/COMPOUND_12.SLDPRT
结构/COMPOUND_13.SLDPRT
结构/COMPOUND_14.SLDPRT
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

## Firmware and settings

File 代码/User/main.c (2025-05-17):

#include "debug.h"
#include "encode.h" // timeapp->encode->main
#include "adc.h"    // timeapp->pwm.screen->Screen_api->adc->main
#include "page.h"
#include "seting.h"

// 待机功耗最低，睡眠功耗其次
// 16k=16,384
// data是表示代码段（text segment）的大小，以字节为单位。代码段包含了程序的可执行指令。
// bss是存储那些在源代码中没有显式初始化的全局变量和静态变量。
// data是显式初始化的全局变量和静态变量

//  ROM：
//  text 段：存储程序代码。
//  data 段：存储已初始化的全局变量和静态变量的初始值。

//  RAM：
//  text 段：在运行时用于存储代码执行（不直接占用 RAM 的存储空间，但需要 RAM 来执行）。
//  data 段：在运行时存储已初始化的全局变量和静态变量。
//  bss 段：在运行时存储未初始化的全局变量和静态变量。

// 2+16k

int main(void)
{

  /*********************基本内容初始化******************************/
  SystemInit();//48000000系统时钟
  NVIC_PriorityGroupConfig(NVIC_PriorityGroup_1);
  USART_Printf_Init(115200); // 串口初始化需要在打印前，不然会卡死3956-3324=600k
  DEBUG_PRINT("\r\nSystemClk:%d\r\n", SystemCoreClock);
  //  DEBUG_PRINT("ChipID:%08x\r\n", DBGMCU_GetCHIPID());
  Delay_Init(); // 延时初始化需要在延时前，不然会卡死4012-3956=100字节

  // 首次才要
  //  FLASH_Unlock();
  //  FLASH_UserOptionByteConfig(OB_IWDG_SW, OB_STDBY_NoRST, OB_RST_NoEN, OB_PowerON_Start_Mode_BOOT);
  //  FLASH_Lock(); //**4232-4012=200字节

  /*********************应用函数初始化******************************/
#if DEBUG_ENABLED != 0
  Check_Reset_Flag(); // 查询复位原因
#endif
  My_GPIO_Init(); // IO口初始化****4484-4232=252字节

#if ENCODER_ENABLED
  TIM2_Init(11, 1); // 编码器的内容,重载值为65535，不分频，1圈12个****6020-6900=880字节输入捕获要500多+定时器300
#endif

  TIM1_Init(100, (SystemCoreClock / (100 * PWM_FRE)) - 1, PWM_Duty); // 参数：预装载值arr(100), 预分频器psc, 初始占空比duty(0-100)
  FAN_SetSpeed(0);
  LED_SetLight(0);

#if SCREEN_ENABLED
  LCD_Drive_Init();    // 屏幕硬件初始化****200字节
  LCD_SHOW_API_INIT(); // 屏幕测试******8404-6224=2180
#endif
#if BATTERY_ENABLED
  Battery_Init(); // 电池的adc初始化****9456-8636=820
#endif
  EXTI_INT_INIT();     // 按键，充电中断初始化
  startup_animation(); // 开机动画

  IWDG_Feed_Init(IWDG_Prescaler_256, 4000); // 该参数必须是介于 0 和 0x0FFF 之间的一个数值    // 4秒不喂狗就复位   低频时钟内部128khz除以256=500,1除以500乘以4000=8s****12467-12356=111字节
#if SLEEP == 1
  AWU_Init(); // 唤醒时间为25/12.5大约是2s左右。
#endif

  while (1)
  {

    if (needSleep)
    {
#if SLEEP == 1
      IWDG_ReloadCounter(); // 喂狗
      Sleep_Scan();         // 检查是否睡觉1
#endif
    }
    else
    {
      show_page();

#if ENCODER_ENABLED
      Encoder_Scan();
#endif

      IWDG_ReloadCounter(); // 喂狗

#if SLEEP == 1
      Sleep_Scan(); // 检查是否睡觉
#endif
      //      Delay_Ms(1000);
    }
  }
}

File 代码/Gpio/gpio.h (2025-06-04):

/*
 * gpio.h
 *
 *  Created on: 2024年9月1日
 *      Author: 12630
 */

#ifndef GPIO_GPIO_H_
#define GPIO_GPIO_H_
#include "ch32v00x_gpio.h"

void My_GPIO_Init();
void My_GPIO_DeInit();


// RGB 灯光控制
#define WS2812_ENABLE  GPIO_ResetBits(GPIOC, GPIO_Pin_4)
#define WS2812_DISABLE  GPIO_SetBits(GPIOC, GPIO_Pin_4)

// 显示屏SPI片选控制
#define  LCD_CS_ENABLE GPIO_ResetBits(GPIOC, GPIO_Pin_7)
#define  LCD_CS_DISABLE GPIO_SetBits(GPIOC, GPIO_Pin_7)


// 显示屏复位控制
#define LCD_RST_0 GPIO_ResetBits(GPIOC, GPIO_Pin_0)
#define LCD_RST_1 GPIO_SetBits(GPIOC, GPIO_Pin_0)

// 显示屏DC控制（数据/命令选择）
#define LCD_DC_0 GPIO_ResetBits(GPIOC, GPIO_Pin_2)
#define LCD_DC_1 GPIO_SetBits(GPIOC, GPIO_Pin_2)

// SPI时钟信号
#define LCD_SCK_0 GPIO_ResetBits(GPIOC, GPIO_Pin_5)
#define LCD_SCK_1 GPIO_SetBits(GPIOC, GPIO_Pin_5)

// SPI数据输出
#define LCD_SDA_0 GPIO_ResetBits(GPIOC, GPIO_Pin_6)
#define LCD_SDA_1 GPIO_SetBits(GPIOC, GPIO_Pin_6)

// 显示屏背光控制
#define LCD_BL_0 GPIO_ResetBits(GPIOC, GPIO_Pin_3)
#define LCD_BL_1 GPIO_SetBits(GPIOC, GPIO_Pin_3)

// 按键检测
#define KEY0 GPIO_ReadInputDataBit(GPIOD, GPIO_Pin_2)

// 充电状态检测
#define CHARGE GPIO_ReadInputDataBit(GPIOC, GPIO_Pin_1)

#endif /* GPIO_GPIO_H_ */

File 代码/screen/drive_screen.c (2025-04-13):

/*
 * drive_screen.c
 *
 *  Created on: 2024年8月30日
 *      Author: 12630
 */
#include "drive_screen.h"

/*********************************************************************
 * @fn      SPI_FullDuplex_Init
 *
 * @brief   Configuring the SPI for full-duplex communication.
 *
 * @return  none
 */
void SPI_FullDuplex_Init(void)
{
    SPI_InitTypeDef SPI_InitStructure = {0}; // SPI 初始化结构体

    // 使能 GPIOC 和 SPI1 的时钟
    RCC_APB2PeriphClockCmd(RCC_APB2Periph_SPI1, ENABLE);

    // 配置 SPI 参数
    SPI_InitStructure.SPI_Direction = SPI_Direction_2Lines_FullDuplex; // 设置为全双工模式
    SPI_InitStructure.SPI_Mode = SPI_Mode_Master;                      // 设置为主模式
    SPI_InitStructure.SPI_DataSize = SPI_DataSize_8b;                  // 数据大小设置为 16 位
    SPI_InitStructure.SPI_CPOL = SPI_CPOL_Low;                         // 时钟极性设置为高**************************一开始设置高哦，因为lora所以修改
    SPI_InitStructure.SPI_CPHA = SPI_CPHA_1Edge;                       // 时钟相位设置为第二个边缘*************一开始设置位第二，因为lora所以修改
    SPI_InitStructure.SPI_NSS = SPI_NSS_Soft;                          // NSS 管脚设置为硬件控制
    SPI_InitStructure.SPI_BaudRatePrescaler = SPI_BaudRatePrescaler_4; // 波特率预分频设置为 64
    SPI_InitStructure.SPI_FirstBit = SPI_FirstBit_MSB;                 // 数据位顺序设置为 MSB 优先

    SPI_InitStructure.SPI_CRCPolynomial = 7; // CRC 多项式设置为 7
    SPI_Init(SPI1, &SPI_InitStructure);      // 初始化 SPI1
    SPI_Cmd(SPI1, ENABLE);                   // 使能 SPI1
}

void SPI_DMA_Tx_Init(DMA_Channel_TypeDef *DMA_CHx, u32 ppadr, u32 memadr, u16 bufsize, uint32_t mode, uint32_t MemoryInc)
{
    DMA_InitTypeDef DMA_InitStructure = {0};

    RCC_AHBPeriphClockCmd(RCC_AHBPeriph_DMA1, ENABLE);

    DMA_DeInit(DMA_CHx);

    DMA_InitStructure.DMA_PeripheralBaseAddr = ppadr;
    DMA_InitStructure.DMA_MemoryBaseAddr = memadr;
    DMA_InitStructure.DMA_DIR = DMA_DIR_PeripheralDST;
    DMA_InitStructure.DMA_BufferSize = bufsize;
    DMA_InitStructure.DMA_PeripheralInc = DMA_PeripheralInc_Disable;
    DMA_InitStructure.DMA_MemoryInc = MemoryInc;
    DMA_InitStructure.DMA_PeripheralDataSize = DMA_PeripheralDataSize_Byte;
    DMA_InitStructure.DMA_MemoryDataSize = DMA_MemoryDataSize_Byte;
    DMA_InitStructure.DMA_Mode = mode;
    DMA_InitStructure.DMA_Priority = DMA_Priority_VeryHigh;
    DMA_InitStructure.DMA_M2M = DMA_M2M_Disable;
    DMA_Init(DMA_CHx, &DMA_InitStructure);

    // 使能DMA传输完成中断
    DMA_ITConfig(DMA_CHx, DMA_IT_TC, ENABLE);

    // 配置NVIC
    NVIC_InitTypeDef NVIC_InitStructure;
    NVIC_InitStructure.NVIC_IRQChannel = DMA1_Channel3_IRQn;
    NVIC_InitStructure.NVIC_IRQChannelPreemptionPriority = 0;
    NVIC_InitStructure.NVIC_IRQChannelSubPriority = 0;
    NVIC_InitStructure.NVIC_IRQChannelCmd = ENABLE;
    NVIC_Init(&NVIC_InitStructure);
}

/*
    简易的us级别的延迟函数
    我的芯片时钟是48Mhz
    一个时钟周期是1/48M=0.020833us,一个机器周期包含12个时钟周期，所以一个机器周期是12*0.020833=0.25us
    所以这里i++运行一次是0.25us，1us大概是运行4次
*/
void delay_us(uint16_t num)
{
    for (uint16_t j = 0; j < num; j++)
    {
        for (uint16_t i = 0; i < 2; i++)
        {
        } // 根据不同的芯片周期修改i的数值
    }
}

u8 Screen_spi_write(uint8_t _dat)
{

    u8 retry = 0;
    while (SPI_I2S_GetFlagStatus(SPI1, SPI_I2S_FLAG_TXE) == RESET)
    {
        retry++;
        if (retry > 200)
        {
            DEBUG_PRINT("send spi outtime!\r\n");
            return 0;
        }

    } // 还没发完
    SPI_I2S_SendData(SPI1, (uint16_t)_dat);

    while (SPI_I2S_GetFlagStatus(SPI1, SPI_I2S_FLAG_RXNE) == RESET)
    {
        retry++;
        if (retry > 200)
        {
            DEBUG_PRINT("rec spi outtime!\r\n");
            return 0;
        }
    } // 还没收完

    return (uint8_t)SPI_I2S_ReceiveData(SPI1);
}

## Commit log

2025-03-31 写产品需求
2025-03-31 准备对代码动手
2025-04-01 io口设置完成，软件设计规范完成
2025-04-01 准备做硬件设计规范
2025-04-01 完成硬件设计规范
2025-04-01 结构设计完成
2025-04-02 修改代码
2025-04-02 做适配新的硬件和界面
2025-04-02 编译成功
2025-04-13 提交结构和代码，开始调试pcba
    [3D_吸烟板_2025-04-10.SLDASM, 3D_吸烟板_2025-04-101.SLDASM, 3D_吸烟板_2025-04-102.SLDASM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]
2025-04-13 界面完成开始调试编码器
2025-04-13 调整刷新，开始调风扇
2025-05-09 开始编写ws2812代码，注意频率被修改了。
    [下壳.SLDPRT, 下壳.STL]
2025-05-09 添加灯光显示，取消跟踪编译文件
2025-05-14 灯光逻辑做好了
    [上壳.SLDPRT, 上壳.STL, 下壳.SLDPRT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]
2025-05-14 最终代码，下个版本需要改一下屏幕cs和rgb的io口
2025-05-14 最后的代码
    [上壳.SLDPRT, 上壳.STL]
2025-05-14 为了正常充电显示
2025-05-17 修复休眠的问题了
2025-05-17 使用不休眠
2025-05-20 修复串口问题
2025-05-29 添加结构爆炸图，修正pcb
    [Board_4.SLDPRT, C0603_5.SLDASM, C0603_5_2.SLDASM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]
2025-06-04 适配新的硬件
    [上壳.SLDPRT, 上壳.STL]
2025-06-21 初始化内容
2025-06-21 修改描述
